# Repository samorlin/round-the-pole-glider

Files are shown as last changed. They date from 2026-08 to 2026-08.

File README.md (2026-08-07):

# Tethered Electric Aircraft

A complete engineering cycle for a tethered electric aircraft designed for circular flight. The project encompassed aerodynamic sizing, hybrid balsa/composite airframe manufacturing, bench power telemetry analysis, and pitch-stability aerodynamic redesign.

---

## Technical Specifications
* **Wingspan & Chord:** 500 mm span, 82 mm chord (Aspect Ratio = 6.1)
* **Aerofoil Profile:** NACA 2412 with 4° incidence and 10° dihedral angle for sideslip stability
* **Fuselage Length:** 284.2 mm (Optimized using Zaic ideal fuselage length criteria)
* **Airframe Materials:** Laser-cut balsa ribs, 3D-printed root/tip impact ribs, 3-layer balsa/plywood sandwich fuselage
* **Main Spar:** 4 mm hollow carbon fiber tube serving as the wing structural spar and tether line pass-through
* **Propulsion:** Single nose-mounted electric motor in puller configuration

---

## Aerodynamic Performance & Flight Testing

Flight data was captured during tethered flight testing using a bench power supply set to a constant 13.0V. 

| Parameter | Takeoff / Acceleration | Steady Cruise | Notes |
| :--- | :--- | :--- | :--- |
| **Current Draw** | 3.2 A | 2.1 A | Drop indicates transition to level cruise |
| **Electrical Power ($P = IV$)** | 41.6 W | 27.3 W | Supplied via bench power unit |
| **True Airspeed (TAS)** | — | 5.88 m/s | Derived from 24.4 RPM tether angular velocity |
| **Estimated Lift / Drag** | — | $L \approx 1.47\text{ N}$, $D \approx 0.67\text{ N}$ | $L/D \approx 2.2$ at cruise |
| **Total Propulsive Efficiency** | — | **14.4%** | Combined motor electrical loss & low-Re prop efficiency |

---

## Engineering Iteration: Pitch Stability Analysis

During the initial flight test, the aircraft experienced low-speed pitch instability and pilot-induced oscillations, leading to a crash landing. 

### Root Cause & Redesign:
1. **Defect:** The original horizontal stabilizer was undersized and located in the wing's downwash zone, causing poor control authority at low speeds.
2. **Aerodynamic Sizing:** Applied the Tail Volume Coefficient formula ($S_t = \frac{V_t \cdot S \cdot c}{l_t}$) to calculate the exact required tail surface area ($S_t$) relative to wing area ($S$), mean aerodynamic chord ($c$), and tail moment arm ($l_t$).
3. **Outcome:** Manufactured a larger, mathematically optimized parallelogram tailplane and converted the assembly to a T-tail layout to clear wing downwash. Subsequent flight tests confirmed full pitch stabilization without low-speed oscillation.

---

## Repository Contents
* `/documentation/` - Final Design Report, Flight Test Performance Report, and Project Gantt Chart.
* `/cad/` - STEP files for airframe, sandwich fuselage layers, and optimized tailplane.
* `/media/` - Photos of flight testing and CAD section views.

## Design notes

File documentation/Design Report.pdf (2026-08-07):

## Design Report

Fuselage Design

The fuselage underwent many changes from initial design concepts to final design. We streamlined the shape significantly to reduce form drag and improve aerodynamic efficiency.

- Geometry & Sizing: The fuselage length was optimised to exactly 284.2mm. This specific dimension was derived using the ideal fuselage length formula
L = 4 × Projected Wing Area as defined by Zaic (1944). We calculated our wing’s projected area (Projected Wing Area = 250mm × cos(10) × 82mm). This length minimises the structural weight, reducing our required lift, whilst ensuring an adequate tail moment arm.
- Wing Positioning: We positioned the wing such that the leading edge of the wings sits at 25% of the total fuselage length away from the nose of the aircraft as this allows a strong moment arm for balancing. (Zaic, F, 1944).
- Structure: We adopted a “sandwich” structure consisting of three layers. The middle layer is made of balsa and has cutouts in strategic areas to save weight and influence the CG. The outer two layers are plywood to provide structural strength as the plywood is stronger and more likely to withstand the impact.
- Surface Finish: The wooden fuselage components are sanded with low-grit sandpaper. This does not remove significant material but ensures a smooth airflow, further reducing skin friction drag.

Wing Design

The wing design was driven by the need for high lift and lateral stability in a fixed circular path.
- Aerofoil & Geometry: We selected the NACA 2412 for its high lift-to-drag ratio. Based on research into RC planes, we chose an aspect ratio of 6, resulting in a wing span of 500mm and a chord of 82mm.
- Incidence: While standard model gliders often use a 2-degree incidence, we increased this to 4 degrees. This higher angle is intended to provide greater lift at low speeds and reduce the risk of stall during tethered flight.
- Stability: A dihedral angle of 10 degrees was chosen to provide lateral stability against the continuous sideslip caused by the circular motion. We opted for a high-wing configuration, utilising the “pendulum effect”, as described by Simons (1999), to further increase our lateral stability and avoid Dutch roll (oscillations in the yaw and roll direction).

Wing Structure

- The wing is composed of 8 ribs. To balance weight and durability, the standard ribs are laser-cut balsa. However, the wing root (which bears the wing's weight) and the wing tips (which are at high risk of ground impact) are 3D printed for enhanced strength as the plastic will be stronger than the balsa, making the glider more durable in the event of a crash.
- Structural rigidity is provided by a 4mm carbon fiber tube acting as the wing spar. This tube runs spanwise through all 8 ribs, distributing aerodynamic loads across the wing. The carbon fibre was used as it is very rigid and already in a tube shape. This spar serves a dual purpose as the tether attachment point. The tether line is threaded directly through the hollow carbon fiber tube. This design choice ensures the tether pulls from the aircraft's center of lift, enhancing stability during circular flight, guided by the principles of circular flight dynamics (Hepperle, 2003).

Tailplane Design

- We considered various designs for our empennage. We initially considered a T-tail (Torode, H, 2010) as they allow for a better glide ratio and they provide more predictable aerodynamic performance (Bruce, K, 2019). However, in the end, we chose to go with a conventional design for several reasons.
- Firstly, the conventional design is lighter than the T-tail. T-tails require a thicker, heavier vertical stabiliser to be able to support the weight of the horizontal stabiliser above it (Scholz, D, 2015). With the vertical stabiliser being a light-weight, thin piece of balsa, we decided it would not be able to support the horizontal stabiliser. The vertical stabiliser is now a part of the fuselage that will be laser cut rather than a separate piece to make it stronger in case of a crash, as they were quick to fall off previously and also to reduce interference drag as there is no join between 2 components, it is all just one.
- Secondly, a conventional rail eliminates the risk of deep stall (Nguyen, D…, 2022).In a T-tail configuration, the high-mounted tailplane can become immersed in the turbulent wake of the main wings during high angles of attack, causing a loss of lift and potentially a stall (SKYbrary, 2026). Finally, our design reduces material usage by cutting parts out of the end of the fuselage at the rear and offers stronger structural integrity, allowing the empennage to be secured more tightly than a T-tail in the event of a crash.

Motor & Propeller Configuration

- Configuration: We chose a single motor in a tractor (puller) configuration mounted on the nose. This arrangement places the motor mass forward, making it easier to align the center of gravity. While a dual-motor setup offers more thrust, the single motor reduces weight and eliminates the risk of asymmetric thrust due to motor misalignment.

- Yaw Compensation: The propeller direction is set counter-clockwise. This ensures that any yaw caused by asymmetric propeller loading acts in the direction the plane is turning around the pole (SKYbrary Aviation Safety, 2021).
- Motor Mount: The mount consists of a 3D-printed shell that fits over the fuselage nose and a mounting plate. It is secured via adhesive and a transverse bar clamping it through the foremost fuselage cutout. We 3D-printed it to ensure its strength and ability to withstand larger loads compared to the woods.

Selection and Use of Materials

- Balsa Wood: Used for the middle fuselage layer and the internal wing ribs. This maximises weight savings in non-load-bearing areas, directly contributing to a lower stall speed.
- Plywood: Utilised for the outer fuselage layers.This provides the necessary rigidity and toughness for the main body to handle the stresses involved during flight.
- 3D Printing (PLA): Used for complex, high-stress components like the wing root and wing tips. This allows for more precise aerodynamic design and impact resistance that laser cutting wood cannot easily provide.
- Vinyl Film: Chosen for the wing skin. It is lightweight and provides a smooth surface finish, reducing skin friction drag.

Parts List
- 4x Plastic Airfoils
- 12x Balsa Airfoils
- Vinyl Wing Skin
- 2x Carbon Wing Spar
- Balsa fuselage middle section
- Balsa horizontal stabiliser
- 2x Plywood fuselage
- Motor Mount
- Motor Mount Support Bar
- Wing Root
- Forward Landing Gear
- Rear Landing Skid
- 4x Bolts for Motor Mounting
- 6x Screws for Wing Mounting
- 10x Screws for Counterweight

### References

- Raymer, D. (2019). AIRCRAFT DESIGN: a conceptual approach. S.L.: Amer Institute Of Aerona, pp. 87-89.
- United States. Federal Aviation Administration (2003). Glider flying handbook. New York, New York: Skyhorse Publishing, p. 3-10.
- Simons, M. (1999). Model Aircraft Aerodynamics. 4th ed. Swanley: Nexus Special Interests, pp. 15-22, 110-115.
- Lennon, A. (1996). Basics of R/C Model Aircraft Design. Ridgefield, CT: Air Age Inc., pp. 25-30.
- Hepperle, M. (2003). Control Line Aerodynamics - Tethered Flight. MH-AeroTools. [Online] Available at: https://www.mh-aerotools.de/airfoils/control_line_aero_1.htm (Accessed: 10 Feb 2026).
- Stackhouse, D. (1998). An Extended Discussion on Roll Control and Stability. [Online] Available at:
https://charlesriverrc.org/articles/design-and-construction/aircraft-design/wing-planform-and-structure/discussion-roll-control-stability/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 he%20aircraft,the%20curvature%20of%20the%20airflow. (https://charlesriverrc.org/articles/design-and-construction/aircraft-design/wing-planform-and-structure/discussion-roll-control-stability/) (Accessed 10/02/26)
- Tang, J. (2021). Technical Manual Series: Brushless Motor Structure and Rotation Principles. [online] blog.orientalmotor.com. Available at: https://blog.orientalmotor.com/technical-manual-series-brushless-motor-structure-and -rotation-principles. (https://blog.orientalmotor.com/technical-manual-series-brushless-motor-structure-and-rotation-principles)
- SKYbrary Aviation Safety. (2021). P-Factor. [online] Available at: https://skybrary.aero/articles/p-factor.
- Zaic, F. (1944). MODEL GLIDER DESIGN, p10. Model Aeronautics Publications, New York [Online] Available at: https://www.gruppofalchi.com/files/06---MODEL-GLIDER-DESIGN-.pdf
- T-Tails: Bruce, K. (2019). Ownership: The tail tale, Aircraft Owners and Pilots Association. [Online] Available at: https://www.aopa.org/news-and-media/all-news/2019/october/pilot/ownership-the-tail-tale (https://www.aopa.org/news-and-media/all-news/2019/october/pilot/ownership-the-tail-tale)
- T -Tails: Torode, H. (2010). Efficient Light Aircraft Design - Options from Gliding, Slide
32. London: Royal Aeronautical Society. [Online] Available at:
- https://www.aerosociety.com/media/6071/4-howard-torode.pdf
- Conventional: Scholz, D. (2015). Aircraft Design: 9 - Empennage General Design, p 9-4. Hamburg: Hamburg University of Applied Sciences. [Online] Available at:
- https://www.fzt.haw-hamburg.de/pers/Scholz/HOOU/AircraftDesign_9_EmpennageG eneralDesign.pdf (https://www.fzt.haw-hamburg.de/pers/Scholz/HOOU/AircraftDesign_9_EmpennageGeneralDesign.pdf)
- Conventional: Nguyen, D. H., Lowenberg, M. H., & Neild, S. A. (2022). Analysing dynamic deep stall recovery using a nonlinear frequency approach, p1180. Berlin: Springer Nature. Available at: https://d-nb.info/1260863085/34
- SKYbrary. (2026) Loss of Control: Deep stall. SKYbrary. Available at:https://skybrary.aero/articles/deep-stall

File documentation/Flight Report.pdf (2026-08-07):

## Group 56 Flight Report

Degree Programme: Aerospace Engineering Module: ELE101 Design, Build and Test Date: 04/05/26
Word Count: 1094

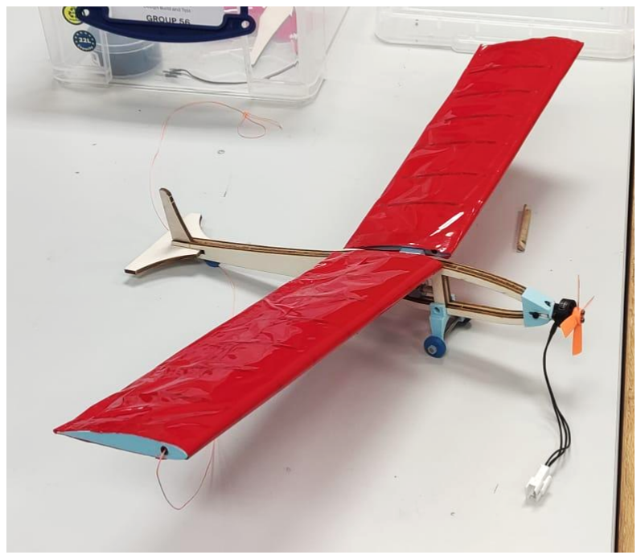
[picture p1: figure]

## Contents:

### Summary of flight performance

For this assignment, two test flights were undertaken. The first flight was done to make sure the glider could fly and to make note of any necessary improvements to the glider’s design. The glider crashed during the first flight and several components needed to be repaired. The second flight was done after changes to the glider’s design were made and allowed for measurements to be taken so that a complete analysis of the flight could be made.

### Results

Table1: Table showing the measured values of voltage, current, revolutions per minute and analysis of the stability of the glider during its flight.
Measurement | Value | Observations
Voltage (Constant) | 13V | Supplied via bench power supply.
Current (Take-off) | 3.2 A | The glider had a fast response time and took off quickly without stalling.
Current (Cruise) | 2.1 A | The glider was flying steadily and was stable.
Revolutions per minute (Controlled flight) | 24.4 | There were no oscillations.
Stability of glider | Stable at high speeds but with a few oscillations at low speeds. | At low speeds there was a bit of pitch instability which caused the glider to oscillate, but at high speeds the glider was very stable in the pitch direction.

### Observations and Improvements

During the second flight test, the variable bench power supply maintained a constant voltage of 13.0V. As a result, the electrical power consumed by the system (P = IV) was directly proportional to the current draw, as it dropped from 41.6 W (3.2A) during takeoff to 27.3W (2.1A) during cruise. This large power reduction indicated that the glider successfully transitioned from acceleration into cruise.

High initial power was required to overcome the inertia of the stationary glider and the increased induced drag of the glider during take-off. Once the aircraft transitioned into a steady cruise the drop in power consumption indicated an optimised lift-to-drag ratio, which allowed the glider to maintain a stable horizontal flight path.

To estimate the aerodynamic efficiency of the glider the TAS was calculated from the angular velocity recorded (24.4RPM), resulting in the cruise velocity being 5.88ms

-1
. In level flight,
the lift was balanced by the weight of the glider. Assuming a mass of around 150g, the lift was approximately equal to 1.47N. By using empirical data on glider testing (ResearchGate, 2025), it was estimated that the glider had a L/D ratio of approximately 2.2. Using this and the estimated lift produced, the drag at cruise speed was approximated to 0.67N. Using this and the TAS (5.88ms

-1
) the aerodynamic power output could be estimated to be approximately 3.94W (P = D × TAS).

Since the electrical power input was 27.3W, the total propulsion efficiency was calculated to be approximately 14.4% (see Appendix 2 for full calculation). The total propulsion efficiency of 14.4%, whilst seemingly low, was the compounded electrical motor loss and propeller aerodynamic inefficiency. Whilst the electric motor likely had a high efficiency, the low Reynolds number increased the relative viscosity of air which led to flow separation and thick boundary layers along the blades, hindering propeller's thrust capability (Brandt and Selig, 2011). Additionally, the propeller was not optimised for the glider's exact cruise advance ratio and, as a result, most of the electrical power input was likely lost overcoming the profile drag of the blades and the parasitic drag of the rapidly rotating tether line.

When designing the glider, the main aim was to achieve as much lift as possible and make the glider as light as possible. As a result, the design of the tailplane was not prioritised which affected the performance of the glider. This was observed during the first test flight, as at low speeds (~1.7 A) the glider was unstable and produced oscillatory motion which resulted in it crashing into the ground. This was due to the glider being unable to respond to small adjustments in speed which led to low precision in the pitch control (Drela, M, 2006).

This was improved by adjusting the shape of the horizontal stabiliser. After conducting some research and focusing on designs that had high success rates, it was decided that its shape should be similar to that of a parallelogram, as shown in Figure 1.

Figure 1 showing examples of gliders with horizontal stabilisers in the shape of a parallelogram:

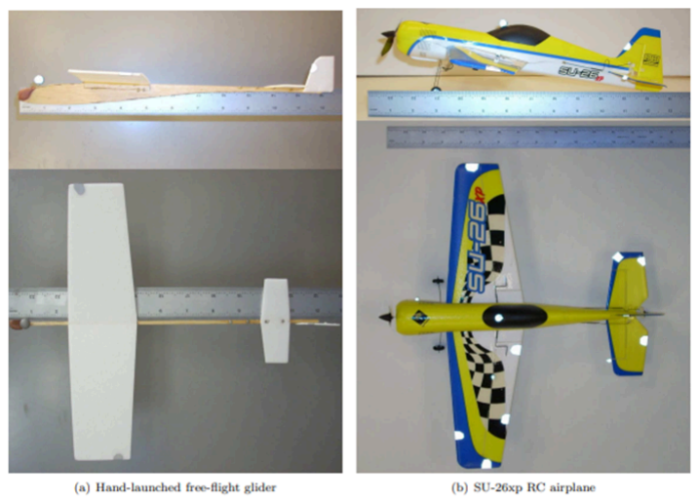
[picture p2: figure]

In order to achieve maximum stability the shape of the stabiliser needed to be optimised mathematically. The calculation for this is shown in Appendix 1.

After finding the dimensions to optimise the shape of the tailplane, a CAD design was created as shown in the figure below.

Figure 2 showing the optimised CAD design of the tailplane

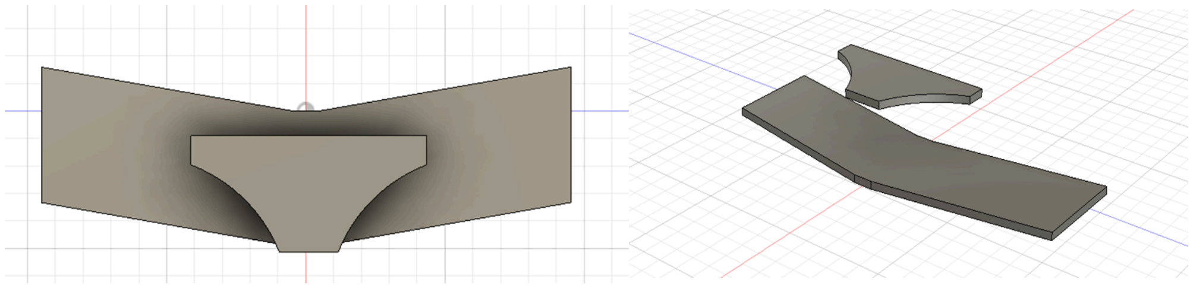
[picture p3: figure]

The new design was significantly larger than the previous one and proportional to the size of the glider which helped to provide better pitch stability. (TU Delft).

Another improvement made to the glider was to add a T-tail. This was done because in the previous design, the horizontal stabiliser was mounted very low on the tailplane, which meant that it was located in the downwash generated from the wings. This was a problem as it caused turbulent air to flow over the stabiliser, creating a loss in lift. As the glider had minimal control surfaces, this also contributed to the oscillatory motion. (Perkins, C.D and Hage, R.E, 1949)

Therefore, placing the stabiliser in a higher location meant that it would no longer be in the wing’s wake, allowing it to increase the glider’s stability.

However, moving the stabiliser to a higher position meant that the vertical stabiliser would need to be thicker and longer to support the weight of the stabiliser. This was taken into account when redesigning the rear empennage as shown in the figure below.

Figure 3 showing the rear empennage CAD design.

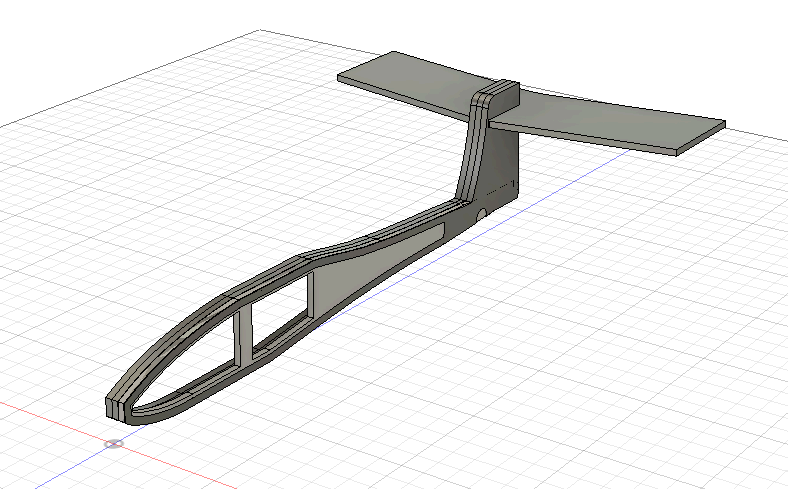
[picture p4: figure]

Another important observation was that at high speeds (~3.2 A), the glider had a large amount of lift and flew at a steady level. This was due to the glider’s centre of mass being placed in a suitable position. This was done by adding an adjustable centre of mass to the glider. The best position to place the centre of mass was determined by making the glider slightly nose heavy as shown in the figure below.

Figure 4 showing the location of the adjustable centre of mass

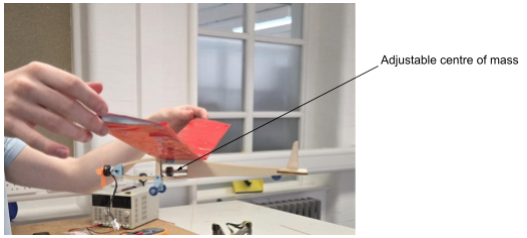
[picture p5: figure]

This greatly benefited the design of the glider as it allowed for improvements to be made. For example, the addition of the T-tail would have shifted the glider’s centre of mass towards the tail, which would have affected its lift and caused it to have pitch instability. Therefore, to avoid this, the centre of mass was made adjustable, allowing the glider to benefit from the addition of the T-tail without compromising lift.

During the first test flight, oscillations caused by the aircraft's inherent instability resulted in a crash that broke the motor mount assembly. For the second flight the design of the motor mount was improved in order to strengthen it, and fix a clearance issue that prevented two of the motor attachment bolts from fitting.

The redesigned motor mount featured a reinforced forward bulkhead, and widened horizontal clearance channels as shown in the figure below. In addition to these changes, the decision to replace the 3D printed transverse bar with a single m3 nut and bolt was made during the build sessions. These modifications were done in order to improve the motors strength and increase its likelihood of surviving a crash as well as making the install process quicker and more simple as no filling was required

Figure 5 showing a CAD model of the redesigned motor mount

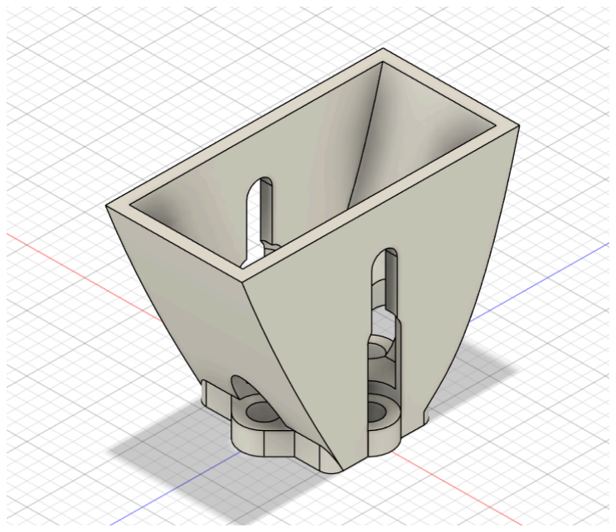
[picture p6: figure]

### References

Drela, M. (2006). Lab 8 Notes – Basic Aircraft Design Rules. [online] MIT OpenCourseWare.
Available | | | | | | | at:
https://ocw.mit.edu/courses/16-01-unified-engineering-i-ii-iii-iv-fall-2005-spring-2006/ffbff8a4985ee6ea819afb90c40834e3_spl8.pdf (https://ocw.mit.edu/courses/16-01-unified-engineering-i-ii-iii-iv-fall-2005-spring-2006/ffbff8a4985ee6ea819afb90c40834e3_spl8.pdf)

Uhlig, D.V. and Selig, M.S. (2011). Stability and Control Characteristics of Micro Air Vehicles
from | Experimental | Measurements. | [online] | illinois.edu. | Available | at:
https://m-selig.ae.illinois.edu/pubs/UhligSelig-2011-AIAA-2011-3820-MAV-Stability.pdf

Merski, J. (1998). A Method for the Analysis of Longitudinal Static Stability of a Flight Vehicle. [online] Wright-Patterson Air Force Base, Ohio: Air Force Institute of Technology. Available at: https://apps.dtic.mil/sti/pdfs/ADA361001.pdf.

Raymer, D.P. (1992). Aircraft Design: A Conceptual Approach. 2nd ed. Washington, D.C.: American Institute of Aeronautics and Astronautics, pp. 76. Available at: http://deadnet.se:8080/Books_and_manuals_on_various_stuff/Science/Physics/Aircraft%20 Design%20-%20A%20Conceptual%20Approach%202nd%20ed.%20-%20D.%20Raymer%2 0%281992%29%20WW.pdf (http://deadnet.se:8080/Books_and_manuals_on_various_stuff/Science/Physics/Aircraft%20Design%20-%20A%20Conceptual%20Approach%202nd%20ed.%20-%20D.%20Raymer%20%2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)

TU Delft (n.d.). Longitudinal Static Stability. [online] tudelft.nl. Available at: https://ocw.tudelft.nl/wp-content/uploads/Hand-out-Stability_01.pdf

Perkins, C.D. and Hage, R.E. (1949). Airplane Performance, Stability and Control. [online]
New | York: | John | Wiley | & | Sons. | Available | at:
https://archive.org/details/airplaneperforma0000perk

ResearchGate. (2025). Effect of Wing Aspect Ratio on the Aerodynamic Performance and Stability of a Balsa Wood Glider. Journal of Applied Aerodynamics, 14(2), 112-121. https://www.researchgate.net/publication/399198626_Effect_of_Wing_Aspect_Ratio_on_the_Aerodynamic_Performance_and_Stability_of_a_Balsa_Wood_Glider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 7ImZpcnN0UGFnZSI6Il9kaXJlY3QiLCJwYWdlIjoicHVibGljYXRpb24ifX0 (https://www.researchgate.net/publication/399198626_Effect_of_Wing_Aspect_Ratio_on_the_Aerodynamic_Performance_and_Stability_of_a_Balsa_Wood_Glider)

Brandt, J.B. and Selig, M.S. (2011). Propeller Performance Data at Low Reynolds Numbers. 49th AIAA Aerospace Sciences Meeting, AIAA Paper 2011-1255.

Appendix 1

In order to achieve maximum stability the shape of the stabiliser needed to be optimised mathematically. This was done by using the equation shown below.
S | [1]
ℎ = V
ℎ
- S
w

·

c
L
ℎ
= Tail Area (mm² S | )
ℎ
V = Volume Tail Coefficient (no units)
ℎ
= Wing Area (mm² S | ) w
c = Chord
L = Tail Moment Arm ℎ

The values of the wing area and chord used were taken from the glider design, the tail moment arm was assumed to be 195mm. This was justified from research which showed that the centre of mass should be of the length down from the nose. The length of the

1
4
glider was 284.2mm, hence the centre of mass is located 213.15mm from the nose, as shown from the calculation below:
284. 2 − (284. 2 × 0. 25) = 213. 15 | [2]

Another assumption used was that the aerodynamic centre of the stabiliser was 20mm, measured from the back of the glider, leading to L being approximately 195mm for ease of
ℎ
design and calculation.

Research showed that the range for V should be between 0.3 and 0.6, however for the
ℎ
glider, 0.55 was chosen. This value was chosen as the oscillations observed in the first test flight were large, so a high volume tail coefficient would increase the static margin and reduce the glider’s oscillations (Merski, J, 1998).

Inputting all the values into equation [1] resulted in the tail area being 9491mm.
To find the span of the stabiliser and the chord, the aspect ratio was needed. The recommended range for the aspect ratio was between 3 and 5 (Raymer, D.P, 1992), so an aspect ratio of 4 was chosen as it is the average. This resulted in the span being 195mm and the chord length being 49mm.

Appendix 2 - Efficiency Calculations

- Initial Parameters & Constants
- Mass (m): 0.15kg
- Angular Velocity (N): 24.4 RPM
- Flight radius (r): 2.3m
- Supply voltage (V): 13 V
- Current at cruise (I ): 2.1 A cruise
- Estimated Lift-to-drag-ratio (L/D): 2.2 (Source: ResearchGate, 2025)
- Acceleration due to gravity ( ): 9.81ms

-2 g

To calculate the True Airspeed (TAS) from the recorded angular velocity (N), the RPM was first converted to angular velocity in radians per second (ω).

ω = N ×

2π
60 = 24. 4RPM ×

2π
60 = 2. 555rad s

−1

TAS = ωr = 2. 555rad s

−1
× 2. 3m ≈ 5. 88ms

−1

The glider was in a steady flight which meant that the lift (L) produced by the glider was balanced by its weight (W).

L = W = mg
L = 0. 150 kg × 9. 81 ms

−2

L = 1. 47N

Using the estimated lift-to-drag ratio of 2.2, the total drag (D) at cruise speed was calculated.

D =

L
L/D =

1.47N
2.2 ≈ 0. 67N

The aerodynamic power output (P ) required to maintain the cruise velocity ( ) is the
out

TAS
product of the drag force and the velocity.

P

out = D × TAS = 0. 67N × 5. 88m/s

P
out

≈ 3. 94W

The total propulsion efficiency (η) is the ratio of the useful aerodynamic power output | (
P ), to the total electrical power input ( = | ), expressed as a percentage as
out

P
in

V × I
cruise
shown below.

η =

P
out
P
in

× 100 =

P
out
V × I
cruise

× 100 =

3.94W
2.1A × 13V × 100

η ≈ 14. 4%

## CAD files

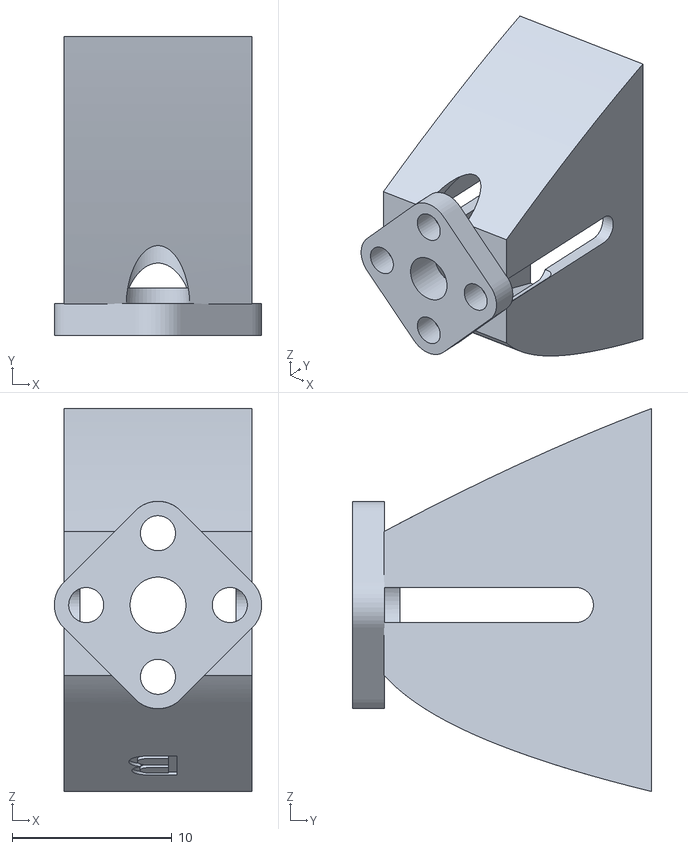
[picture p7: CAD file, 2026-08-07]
cad/Motor Mount Main.stl
13.0 x 18.7 x 24.0

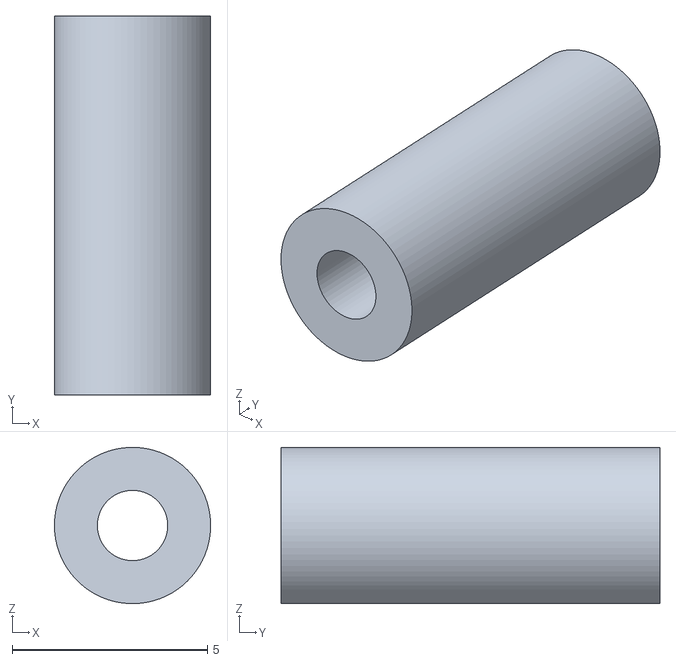
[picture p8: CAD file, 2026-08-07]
cad/Motor Mount Bar.stl
4.00 x 9.70 x 4.00

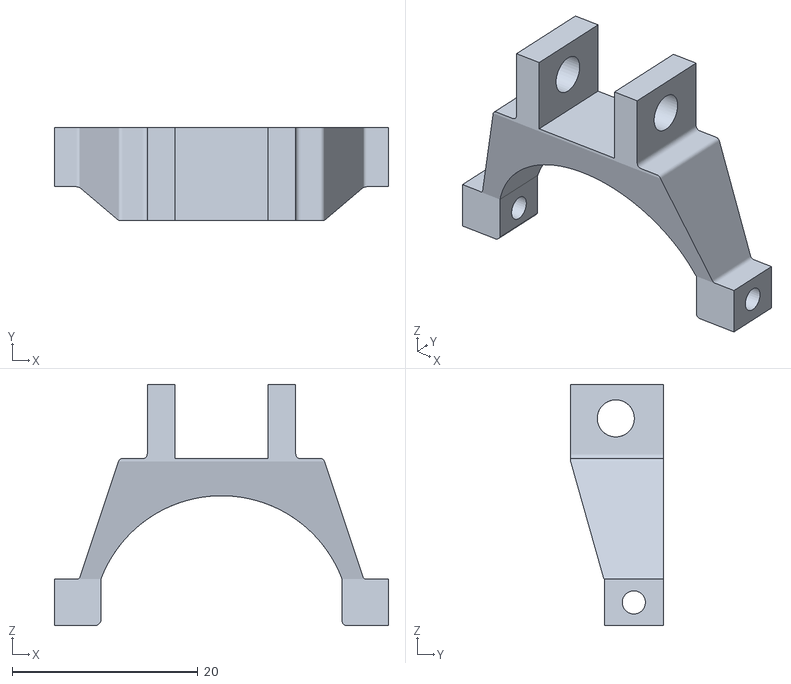
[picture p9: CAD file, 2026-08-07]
cad/landing gear.stl
36.0 x 10.0 x 26.0

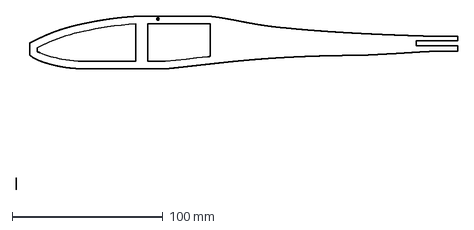
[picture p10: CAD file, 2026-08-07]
cad/Ply Wood Cut Out Laser Cut .dxf
293.4 x 115.0 mm

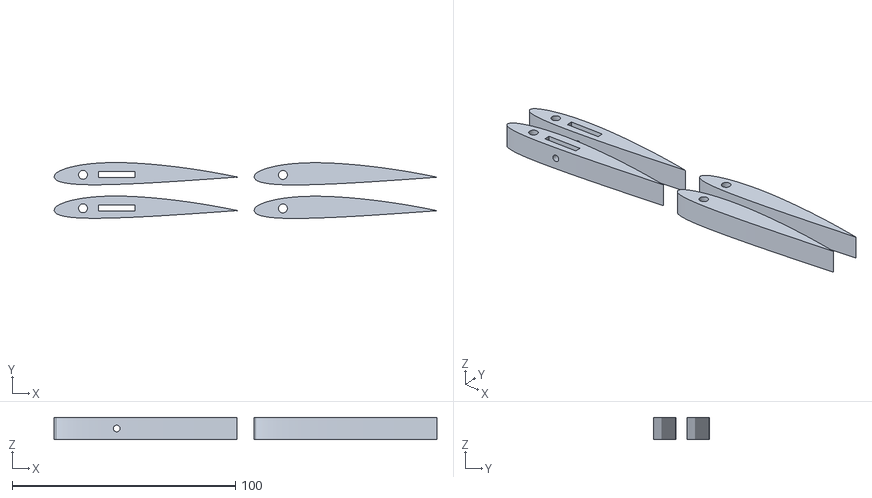
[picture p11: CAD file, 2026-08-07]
cad/AIRFOILS .stl
171.5 x 25.0 x 10.0

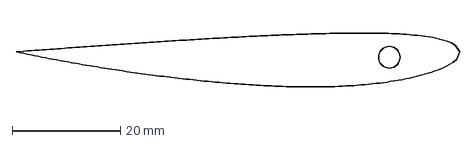
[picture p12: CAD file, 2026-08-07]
cad/balsa airfoil rib (12 needed).dxf
82.0 x 9.97 mm

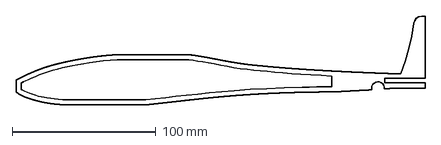
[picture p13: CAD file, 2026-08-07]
cad/Balsa Laser Cutter Cut Out.dxf
284.2 x 61.7 mm

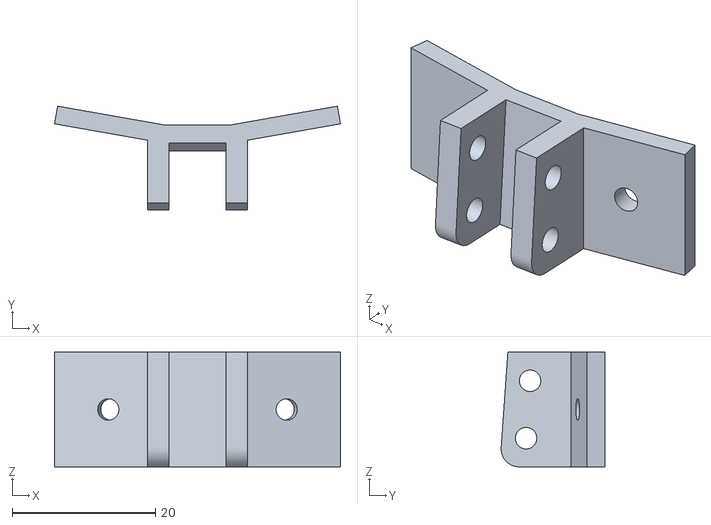
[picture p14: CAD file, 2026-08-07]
cad/GDP wing joiner.stl
39.9 x 14.5 x 16.0
